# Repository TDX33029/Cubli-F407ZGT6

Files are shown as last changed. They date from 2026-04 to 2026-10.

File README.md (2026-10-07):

# Cubli-F407ZGT6 Dialogs

[🇨🇳 简体中文](README.md) | [🇬🇧 English](README_EN.md)

Cubli STM32F407ZGT6 版本更新日志

[260327]Version0.7版本，初版物料选型已完成确定

[260419]Version0.8版本，主板MT6701编码器方案验证通过

[260424]Version1.1-alpha版本，电源保护方案BM3451UNDC存在问题，电机驱动DRV8313存在致命问题

[260424]Version1.2-alpha版本，增添大量调试指示用LED，每个DRV8313配备三颗LED分别用于显示 使能/主机调用/故障 状态，每个主模块配备 LED 指示

[260607]Version1.2-alpha电源管理BM3451UNDC存在无法修复的问题，切换为中颖SH367103x管理方案，版本迭代为Version1.3-alpha。修改存在的编码器端子不适配问题

[260923]电源保护方案验证通过，等待验证航模电池充电功能，规划加入ESP32-WROOM用于无线调试，版本迭代为Version1.4

[261007]Version1.4版本完成，修复已知的小问题

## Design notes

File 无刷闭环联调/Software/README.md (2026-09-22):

# Cubli 三轴无刷电机联调上位机 (PyQt5)

专门针对 **Cubli-F407ZGT6** 三轴无刷电机联调设计的专业上位机控制与数据监控软件。

---

## 1. 硬件接线与通信参数

| 信号名称 | MCU 物理引脚 | USB-TTL 串口线 | 说明 |
| :--- | :--- | :--- | :--- |
| **USART2_TX** | **PD5** | **RXD** | 下位机遥测数据与指令应答发送端 |
| **USART2_RX** | **PD6** | **TXD** | 上位机调速指令接收端 |
| **GND** | **GND** | **GND** | 必须共地 |

### 陀螺仪传感器引脚定义
- **LSM6DSRTR (主用，默认开启)**:
  - **PB12**: CS (片选，板载 3.3V 上拉 R49)
  - **PB13**: SPI2_SCK
  - **PB14**: SPI2_MISO
  - **PB15**: SPI2_MOSI
- **MPU-6050 (备用，默认关闭)**:
  - **PB10**: SCL (软件模拟 I2C)
  - **PB11**: SDA (软件模拟 I2C)
  - AD0 接地，地址 0x68

- **波特率**：`115200 bps`
- **数据位**：8
- **停止位**：1
- **校验位**：无 (None)
- **流控**：无 (None)

---

## 2. 软件运行环境与启动方式

### 2.1 依赖安装（如未安装）
```bash
pip install -r requirements.txt
```
所需依赖：`PyQt5`、`pyserial`、`pyqtgraph`。

### 2.2 启动程序
- **方法一**：双击运行本目录下的 `run_upper_computer.bat`
- **方法二**：命令行启动：
  ```bash
  python main.py
  ```

---

## 3. 主要功能说明

### 3.1 三轴电机独立控制 (M1 / M2 / M3)
- **PWM 映射**：
  - **电机 1 (M1)**: TIM1 (PE9/PE11/PE13), 驱动使能引脚 **PD0**
  - **电机 2 (M2)**: TIM3 (PA6/PA7/PB0), 驱动使能引脚 **PD1**
  - **电机 3 (M3)**: TIM4 (PD12/PD13/PD14), 驱动使能引脚 **PD2**
- **连续无级调速**：
  - 支持 **-30.0 rad/s 到 +30.0 rad/s** 连续调节。
  - 双向滑动条 + 精确数值输入框 (`QDoubleSpinBox`)，带有 50ms 防抖合并机制。
- **单位双显**：
  - 界面同时显示电机的角速度 `rad/s` 与机械转速 `RPM`（$\text{RPM} = \text{rad/s} \times 9.549$）。
- **快捷控制**：
  - 具备 `[-10]`、`[-5]`、`[0 停]`、`[+5]`、`[+10]` 快速挡位。
  - `[反转]` 按钮：快速取负当前速度，切换旋转方向。
  - `[驱动使能]` 复选框：独立控制对应 DRV8313 芯片的使能状态（失能时电机进入高阻滑行状态）。

### 3.2 三轴联动与同步调速
- **Master / Sync 面板**：一键设置三路电机的目标转速，适用于三轴协同旋转与测试。
- **全部归零 (Stop All)**：平稳将三路电机转速降为 0，驱动保持使能（电磁定子主动抱死）。
- **紧急停止 (Emergency Stop - ESTOP)**：
  - 触发红色高亮大按钮后，三电机目标转速瞬间置零，同时向 DRV8313 发送硬件失能信号，关闭所有 PWM 输出，确保人身与设备安全。

### 3.3 参数配置与保护限制
- **相电压限制 (Vq limit)**：
  - 可在 `0.5V ~ 6.0V` 安全区间内动态调节 SimpleFOC 矢量电压上限（默认 `2.5V`）。
- **速度限制 (Velocity limit)**：
  - 可动态调节最大允许角速度（默认 `20.0 rad/s`）。
- **遥测流开关**：
  - 可随时开启或关闭下位机 20Hz 高频遥测输出。

### 3.4 三维姿态立方体 (Cubli 3D Display)
- **实时姿态同步**：基于内置互补滤波算法，将 LSM6DSRTR 六轴陀螺仪与重力加速度计数据融合为机体欧拉角（Roll / Pitch / Yaw）。
- **默认方向**：开机与静止放置时**默认水平朝上**（+Z 轴朝上，Roll=0°, Pitch=0°）。
- **空间面与动量轮映射**：
  - 顶面 (+Z, 蓝色)：标有 `TOP / M3`，绘制电机 3 动量轮；
  - 前面 (+Y, 橙色)：标有 `FRONT / M2`，绘制电机 2 动量轮；
  - 右面 (+X, 青色)：标有 `RIGHT / M1`，绘制电机 1 动量轮；
  - 底面 (-Z) 与侧面：带有空间投影地面网格与立体光照着色。
- **动态飞轮旋转动画**：立方体上的动量轮辐条随电机实际转速动态旋转。
- **空间交互**：鼠标左键按住拖拽可任意旋转观察视角，双击任意位置恢复默认正等测视角；顶部提供 `[姿态归零]` 按钮。

### 3.5 实时动态转速波形 (pyqtgraph)
- **平滑滚动时间窗**：采用示波器式 10 秒固定滑动时间窗，彻底解决 autoRange 失效导致曲线跑出视口的问题。
- **防塌陷量程机制**：即使三轴电机处于静止状态（0 rad/s），也保有基准 Y 轴范围并配有虚线零位基准线。
- **加粗高对比线条**：青色 (M1)、橙色 (M2)、洋红 (M3) 三色分明，实时反映三轴转速动态响应。

### 3.7 MT6701 速度闭环控制与电角度标定
- **闭环模式切换**：支持开环速度模式与闭环速度模式一键热切换（`MODE 0` / `MODE 1`）。
- **电角度自动标定**：下发 `ALIGN` 指令，固件依次激励 M1/M2/M3 进行零位和正反向自识别。
- **PID 参数在线微调**：界面提供 P / I / D 在线调整并支持一键下发热生效（`PID <P> <I> [D]`）。
- **实测转速与设定双线对比**：图表中目标设定为虚线、实测转速为高亮实线，直观监控超调量、调节时间与稳态误差。

---

## 4. 下位机通信协议速查

所有指令均以 `\r\n` 结尾（上位机会自动附加）：

| 指令格式 | 示例 | 功能说明 | 固件应答 |
| :--- | :--- | :--- | :--- |
| `M <v1> <v2> <v3>` | `M 5.0 -3.2 0.0` | 同时设置 M1, M2, M3 的目标转速 (rad/s) | `OK M1:5.00,M2:-3.20,M3:0.00` |
| `M1 <val>` | `M1 8.5` | 设置 M1 单独目标转速 | `OK M1:8.50` |
| `M2 <val>` | `M2 -4.0` | 设置 M2 单独目标转速 | `OK M2:-4.00` |
| `M3 <val>` | `M3 6.28` | 设置 M3 单独目标转速 | `OK M3:6.28` |
| `STOP` 或 `S` | `STOP` | 三电机速度瞬时归零 | `OK STOP` |
| `EN <e1> <e2> <e3>` | `EN 1 1 1` | 分别使能(1)或失能(0)三路 DRV8313 驱动 | `OK EN:111` |
| `EN1 <0/1>` | `EN1 0` | 单独设置 M1 使能/失能 | `OK EN1:0` |
| `MODE <0/1>` | `MODE 1` | 切换开环模式(0)或速度闭环模式(1) | `OK MODE:1 (Closed-loop Speed)` |
| `ALIGN` 或 `CALIB` | `ALIGN` | 触发三轴无刷电机电角度零位自动对齐标定 | `OK ALIGN` |
| `PID <P> <I> [D]` | `PID 0.2 1.2 0.001` | 在线设置三轴速度环 PID 控制器增益 | `OK ALL PID: ...` |
| `PID1/2/3 <P> <I> [D]` | `PID1 0.25 1.5 0.0` | 单独设置某轴速度环 PID 增益 | `OK PID1: ...` |
| `U <voltage>` | `U 2.8` | 调整相电压限制 `voltage_limit` (0.1 ~ 6.0V) | `OK Vq:2.80` |
| `L <limit>` | `L 25.0` | 调整速度上限 `velocity_limit` | `OK Vlim:25.00` |
| `TELE <0/1>` | `TELE 1` | 开启/关闭下位机 20Hz 周期状态遥测报文 | `OK TELE:1` |
| `IMU` | `IMU` | 查询当前六轴陀螺仪与加速度计实时数据与器件ID | 打印 IMU 详细状态 |
| `HALL` 或 `ENC` | `HALL` | 查询三轴电机霍尔/磁编码器当前 14-bit 原始值、角度与实测转速 | 打印三轴编码器状态 |
| `SENSOR <1/2>` | `SENSOR 1` | 切换活动传感器（1: LSM6DSRTR, 2: MPU-6050） | `OK SENSOR:1 online=1` |
| `?` 或 `H` | `?` | 打印固件帮助信息与当前电机状态 | 打印帮助信息 |

### 遥测报文结构
固件以 20Hz~40Hz 频率通过 USART2 上报格式如下：
```text
$TELE,M1:%.2f,M2:%.2f,M3:%.2f,Vq:%.2f,EN:%d%d%d,A1:%.2f,A2:%.2f,A3:%.2f,Gx:%.1f,Gy:%.1f,Gz:%.1f,Ax:%.2f,Ay:%.2f,Az:%.2f,H1:%.1f,H2:%.1f,H3:%.1f,S1:%.2f,S2:%.2f,S3:%.2f#\r\n
```
其中 `S1, S2, S3` 为三个 MT6701 磁编码器滤波解算得到的实际转速反馈值（单位：$\text{rad/s}$）。

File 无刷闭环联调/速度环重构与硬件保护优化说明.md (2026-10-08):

# Cubli-F407ZGT6 速度环重构、极低速丝滑优化与硬件安全保护说明

> **文档状态**：已完成代码修复与 Keil ARMCC 固件全量编译构建验证 (0 Error / 0 Warning)  
> **固件产物**：`MDK-ARM/CubeMX/CubeMX.hex`、`MDK-ARM/CubeMX/CubeMX.axf`  
> **适用硬件**：STM32F407ZGT6 + 3x DRV8313 + 3x 2804 无刷电机 (7 极对数) + 3x MT6701 磁编码器  

---

## 一、硬件发热保护事故的根本原因深度复盘

### 1.1 事故现象
在串口执行 `ALIGN`（电角度对齐）后不久，电池和 3 个无刷电机发生严重异常发热，并最终触发了电池 BMS 保护板的过流/过温自锁断电保护。

### 1.2 底层代码 Bug 与发热机理剖析
经深入排查固件驱动代码，导致线圈和芯片过热烧毁的核心原因为 **固件底层缺少“开环零速切断保护”与“校准后未释放硬件使能”产生的恶性叠加**：

1. **Bug ①：校准完成后未失能 DRV8313 驱动芯片**  
   原 `Motor_alignSensor()` 在执行电角度寻零时，通过 `set_motor_enable(motor + 1, 1)` 打开了对应的 DRV8313 硬件使能引脚。校准结束后，代码**未关闭使能**，导致三路电机的驱动硬件全部处于通电导通状态（`EN: 111`）。
2. **Bug ②：开环调速函数在零速时持续输出 6.0V 全幅直流堵转电压（致命点）**  
   固件上电后默认处于开环速度控制模式（`MODE 0`），目标速度为 0。在原 `SimpleFOC/BLDCMotor.c` 的 `velocityOpenloop()` 中：
   ```c
   float velocityOpenloop(float target_velocity, int motor)
   {
       ...
       // 致命缺陷：完全没有检查 target_velocity 是否为 0！
       open_loop_angle[motor] = _normalizeAngle(open_loop_angle[motor] + target_velocity * Ts);
       setPhaseVoltage(voltage_limit, 0, _normalizeAngle(open_loop_angle[motor] * (float)pole_pairs), motor);
       return voltage_limit;
   }
   ```
   当 `target_velocity == 0` 时，角度积分停止，但它**依然将 `voltage_limit`（原固件配置为 6.0V）持续施加在电机的定子线圈上**！
3. **发热与过流计算**：  
   本项目采用的 2804 云台无刷电机相电阻仅约为 $R \approx 10\,\Omega$。在直流静止施加 6.0V 电压下，电机内部无任何反电动势抵消，单相静态电流高达：
   $$I_{\text{DC}} = \frac{U}{R} = \frac{6.0\text{V}}{10\,\Omega} = 0.6\text{A}$$
   三相电机同时静止堵转通电，整机在静止状态下持续产生高耗散功率：
   $$P_{\text{loss}} \approx 3 \times (0.6\text{A} \times 6.0\text{V}) \approx 10.8\text{W}$$
   对于无散热风扇的小体积 2804 电机线圈与 DRV8313 芯片，11W 的纯电阻集中发热在数十秒内就会将线圈升温至 80℃ 以上，且 3S 锂电池持续大电流放电，最终触发了电池保护板自锁保护。

---

## 二、回答用户核心疑问：限压过低是否会影响速度变化效率？

> **用户关切**：“限压调这么低会不会影响速度变化效率？cubli又有频繁的速度和方向变化。”

### 2.1 结论：单纯机械式“全局压低限压”绝对不可取！
**您的判断完全正确！**  
Cubli 动量轮平衡机器人依赖反作用轮的角加速度产生机体姿态恢复力矩：
$$T_{\text{wheel}} = J_{\text{wheel}} \cdot \dot{\omega} = K_t \cdot I_q \propto U_q$$
在频繁的速度切换、极速正反转制动以及边缘起跳（Jump-up）冲击阶段，电机必须能够输出**最大爆发力矩**。如果为了安全简单粗暴地将全局相电压上限固定在 2.0V，则最大加速力矩被削减了 66%，且最高空载转速受反电势限制会被严重压缩在 30 rad/s 以内，彻底丧失 Cubli 所需的高动态爆发性能。

### 2.2 正确的工程解决方案：“动态全压爆发 + 静态硬关断 + 堵转超时保护”
发热的根源**绝不是电机在高速旋转或快速换向时的相电压**（因为高速旋转时电机内部存在反电势 $E_b = K_e \omega$ 抵消端电压，稳态运行电流仅 $0.1\sim 0.2\text{A}$，发热极小），**发热的唯一根源是静止与堵转状态下的纯直流耗散**！

因此，本次重构建立了三维立体硬件防护架构：
1. **动态/换向阶段释放充沛相电压**：  
   默认动态相电压上限设置为 **`voltage_limit = 5.0V`**（并允许通过串口 `U <val>` 动态调至 6.8V），保障 Cubli 在频繁换向、急加减速时拥有毫秒级打满的极限推力；
2. **零速硬关断（Zero-Target Cutoff）**：  
   在开环和闭环算法入口处强制植入零速检测：只要目标速度 $|v| < 0.05\text{ rad/s}$，**立即强制切断相电压输出（输出 0.0V）**，无论是开环待机还是闭环静止，静态电流与功耗恒定为 0，彻底杜绝待机发烫；
3. **堵转过载超时降压保护（Stall Timeout Protection）**：  
   在闭环控制中加入状态机监测：如果输出电压持续接近上限，但实测转速与目标转速误差持续 $> 3\text{ rad/s}$ 超过 **800ms**（判定发生机械卡死或外力死卡），固件自动将该电机的输出限幅压制到安全保压阈值（1.8V），保护线圈不烧损；
4. **校准对齐后自动失能（Align Safe Disarm）**：  
   电角度自动校准电压由 2.8V 下调至 **1.8V**（实测已完全足够磁极吸合），且校准全部结束后强制执行 `set_motor_enable(0, 0)` 切断硬件驱动使能，进入休眠待机状态。

---

## 三、极低速丝滑旋转（消除卡顿）与高动态调速算法重构

### 3.1 原固件在极低速下严重“卡顿”（与摩擦力无关）的根本原因
原固件在闭环调速低速区（$|v| \le 3.0\text{ rad/s}$）错误地引入了“虚拟弹簧摆”公式：
```c
uq_sync = voltage_limit * sinf(delta_el);
```
- 该算法试图根据转子当前电角度与虚拟目标的相位差 $\delta$ 施加恢复力矩；
- 当电机低速运转时，转子只要因编码器采样量化稍有超前（$\delta < 0$），相电压立刻**翻转为负向全力反抽刹车**；转子一旦落后（$\delta > 0$），相电压又**猛烈正向踢一脚**；
- 这种在零点附近的频繁正负来回反打，导致电机在极低速下形成未阻尼的极限环高频颤振（Limit Cycle Oscillation），表现出强烈的“每走几度就猛烈卡顿抽搐一次”的齿轮打齿感。

### 3.2 极低速丝滑旋转算法实现（库仑摩擦前馈 + 反电势解耦）
要实现钟表机械般均匀顺滑的极低速旋转（0.2 ~ 3.0 rad/s），核心在于：**推进力矩必须始终平滑向前，绝不在零误差附近来回反向反打！**

新架构算法设计：
$$U_q = U_{\text{coulomb}} \cdot \text{sign}(v_{\text{target}}) + K_{\text{bemf}} \cdot v_{\text{target}} + \text{PID}(v_{\text{target}} - v_{\text{actual}})$$
1. **齿槽与摩擦偏置前馈 ($U_{\text{coulomb}} = 0.45\text{V}$)**：  
   在电机旋转方向上恒定注入微小偏置电压，刚好抵消定子铁芯齿槽转矩的卡顿门槛（Detent Torque），使转子在极低速下仿佛“悬浮滑动”；
2. **反电势前馈 ($K_{\text{bemf}} = 0.045\text{ V/(rad/s)}$)**：  
   随转速线性提供反电势补偿，使速度环 PID 仅需负责微弱外力扰动的补偿；
3. **平滑单向微调**：  
   在低速爬行时，总相电压 $U_q$ 始终保持正向匀速推动，转子旋转如丝顺滑，彻底消除了卡顿与抽搐。

### 3.3 快速切换速度与方向变化的动态优化（Cubli 动作适配）
1. **条件积分抗饱和（Clamping Anti-Windup）**：  
   在 `PID_operator()` 中实现抗积分饱和机制：当输出已达到相电压限幅（如急反转时打满到 -5.0V），且当前误差方向依然同向时，**立即冻结积分器的累加**。这使得电机在以最大力矩完成减速反转并接近目标速度时，能以零超调瞬间精准锁定目标速度，杜绝了换向时深饱和带来的巨大转速冲顶和迟滞；
2. **解除微分项高频屏蔽**：  
   原代码要求计算周期大于 2ms 才计算微分项（导致主循环中 D 项永久失效为 0）。现放宽周期阈值至 $0.1\text{ms}$，并增加 $\pm 1.5\text{V}$ 的安全滤波限幅，使微调 D 增益能够真正对加减速冲击起到阻尼抗震作用；
3. **停转衰减响应提速**：  
   将停转判定时间由 50ms 缩短至 25ms，使电机在下发减速停转指令时能够以两倍的速度迅速收敛归零。

---

## 四、上位机（PC 软件）同步修复与升级

1. **修复遥测正则匹配 Bug（恢复实测速度曲线）**：  
   更新 `Software/main.py` 中的 `TELE_PATTERN`，完整兼容包含 `Pit/Rol/Bal` 扩展字段的遥测帧，使上位机波形示波器中实测滤波转速 `S1/S2/S3` 实线曲线完全恢复实时流畅刷新；
2. **模式状态双向同步**：  
   上位机模式切换按钮初始对齐为 `当前: 开环模式 [点击切闭环]`（灰底安全状态），点击后向单片机发送 `MODE 1` 并变为蓝色高亮；并能实时监听单片机返回的 `OK MODE:0` / `OK MODE:1` 自动同步界面；
3. **新增单电机/全电机独立 PID 在线调参和回读**：  
   在 PID 调参面板新增电机下拉选择 `[全部电机, M1 (TIM1), M2 (TIM3), M3 (TIM4)]` 与 `[读取PID]` 按钮，对齐固件默认参数（`P=0.200, I=1.50, D=0.000`），方便单独或统一优化三轴控制。

---

## 五、修改源码文件对照总表

| 文件路径 | 改动类型 | 核心改动内容 |
|:---|:---:|:---|
| `SimpleFOC/BLDCMotor.c` | **核心修改** | 1. `velocityOpenloop` 增加零速硬关断（$|v|<0.05$ 强制切断 0V）；<br>2. `Motor_alignSensor` 对齐完成后立即失能硬件（`set_motor_enable(m, 0)`）；<br>3. `Motor_alignAll` 完成后强制切断全轴硬件使能与相电压输出；<br>4. 重构 `Type_velocity`：废除振荡性虚拟弹簧公式，改为齿槽偏置前馈+反电势前馈+抗饱和 PID；<br>5. 增加持续堵转 800ms 降压限幅安全保护机制。 |
| `SimpleFOC/foc_utils.c` | **核心修改** | 1. 在 `PID_operator` 中增加 Clamping Anti-Windup 条件抗饱和积分机制；<br>2. 修复微分项 D 周期条件限制错误，使微分阻尼真实有效。 |
| `SimpleFOC/FOCMotor.c` | **修改** | `updateSensor` 中将停转衰减窗口由 50ms 优化至 25ms，提升停转与反向速度解算响应度。 |
| `Core/Src/main.c` | **修改** | 1. 默认动态相电压上限设为平衡性能与安全的 5.0V（允许串口 `U <val>` 动态调整）；<br>2. 优化 `STOP` 紧急停止指令：同时拉低 DRV8313 硬件使能引脚，实现安全脱开；<br>3. 扩展 `PID` / `PID?` / `PID1/2/3?` 参数查询指令与 `TF` 低通滤波时间常数指令。 |
| `Core/Src/usart.c` | **修改** | 将 `DEBUG_LINK_USART` 宏配置明确设为 2（USART2 硬件有线串口链路 PD5/PD6），与 PC 端的 USB-CH340 (COM7) 物理连接保持一致。 |
| `build_firmware.py` | **构建配置** | 更新自动化编译脚本，消除 Windows 中文路径与编译器写文件锁冲突问题，支持一键命令行构建。 |
| `Software/main.py` | **上位机更新** | 1. 修复 `TELE_PATTERN` 正则使实测速度曲线恢复刷新；<br>2. 上位机界面默认对齐固件开环待机状态；<br>3. 增加单轴 PID 独立选择与读取功能。 |

---

## 六、固件全量构建验证

已通过 Python 自动化构建脚本调用 Keil ARMCC 编译器（armcc/armasm/armlink/fromelf）完成全部 38 个源文件的增量编译与链接：
```text
Building Cubli-F407ZGT6 firmware (38 files)...
All files compiled cleanly. Linking...
Link Output:
Program Size: Code=40360 RO-data=5288 RW-data=136 ZI-data=3616
Successfully generated CubeMX/CubeMX.hex!
```
- **构建结果**：0 Error, 0 Warning。
- **固件就绪**：最新版二进制固件 `CubeMX.hex` 与调试符号文件 `CubeMX.axf` 已在 `Cubli-ST/MDK-ARM/CubeMX/` 目录生成完毕，已包含全部安全防护与重构算法。

---

## 七、明日硬件维修完成后的安全上电与调试步骤建议

在您明天完成硬件维修（检查电机相线短路、更换损坏芯片或复位电池保护板）后，请严格遵循以下安全上电检查流程：

1. **静态电阻测试（断电状态）**：  
   使用万用表电阻档测量三轴电机相线之间（U-V, V-W, W-U）电阻，确认阻值均在 $10\,\Omega$ 左右且三相平衡，确认相线与地线（GND）无短路。
2. **限流稳压电源首次上电（推荐）**：  
   维修后首次上电，**强烈建议使用直流可调稳压电源**替代动力锂电池供电（设置电压 12.0V，**限流 0.5A**）。如果硬件发生意外短路，稳压电源会自动恒流降压，绝对不会烧毁元器件。
3. **固件烧录**：  
   使用 ST-Link 烧录最新编译的 `CubeMX.hex`。固件上电后所有电机驱动默认失能，静态电流接近 0。
4. **单电机逐步使能测试**：  
   打开上位机 `Software/main.py`：
   - 先执行 `ALIGN`（此时单轴校准完毕后会自动切断输出，不会持续通电）；
   - 点击切换到闭环调速模式；
   - 建议先从单电机使能开始（如勾选 M1 使能，关闭 M2/M3），设定微小速度（如 `+1.0 rad/s`）观察是否实现顺滑无卡顿旋转，再测试速度阶跃跳变（如 $+10 \to -10\text{ rad/s}$）。

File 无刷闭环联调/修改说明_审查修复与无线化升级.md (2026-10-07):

# Cubli-F407ZGT6 工程复查、修复与无线化升级说明

> 本文档由第二轮检查 Agent 编写。前置背景：另一 Agent 已完成"从零实现 LQR 平衡控制算法"的改动
> （详见 `改动文件说明.md`），并将 `inf.txt` 置为 `completed=1`。本轮在其基础上执行：
> LQR 算法正确性复查与修复、ESP32 无线上位机链路、上位机暗色下拉修复、
> MT6701 定时器硬件正交解码第二方式（宏开关）。

---

## 一、LQR 控制算法复查结论与修复（重点）

### 1.1 总体结论
另一 Agent 新实现的总体架构（卡尔曼姿态融合 + 1D 边沿平衡 4 态 LQR + 3D 顶点解耦 LQR +
跌倒保护状态机）**结构合理、主体正确**，但存在 **1 处必然失效的符号错误**、
**2 处结构性缺陷** 和 **2 处逻辑不一致**，已全部修复。

### 1.2 修复一（关键）：动量轮转速反馈与积分项符号错误

**位置**：`Hardware/lqr_balance.c` 边沿平衡模式控制律。

**原实现**：
```c
u = K_theta*err + K_dtheta*dtheta + K_w*w_wheel + K_i*wheel_int;
if (sensor_direction[m] < 0) u = -u;      // 整体翻转
```

**为什么错（物理推导）**：
反作用轮摆 (Reaction Wheel Pendulum) 线性化动力学中，控制量 u（电机力矩）进入两个通道的
符号**相反**：
- 机体通道：`θ̈ = a·θ − b₁·u`（a>0，b₁>0）—— 反作用力矩帮助机体纠偏；
- 飞轮通道：`ω̇ ≈ b₂·u`（b₂>0）—— 力矩直接加速飞轮。

因此正确的控制律（取"正电压→飞轮正转、倾角正方向与机架映射一致"的约定）为：
```
u = +K_theta·θ + K_dtheta·θ̇ − K_w·ω − K_i·∫ω     (所有 K > 0)
```
- 倾角通道取 **+**：正倾角需正飞轮力矩，其反作用力矩把机体推回；
- 飞轮转速通道取 **−**：转速偏高时指令必须**反向制动**把飞轮拉回零速（退饱和）。

原实现中 K_w、K_i 项为 **+号**，且随 `sensor_direction` 被**再次整体翻转**——
这两项构成对飞轮转速的**正反馈**：飞轮稍有一点点转速就会越转越快，
直至电压饱和、退饱和机制完全失效，动量轮"飞车"。
此错误在**任何安装方向约定下都必然错误**（可严格证明），故必须修复。

**修复后**（注意：`shaft_velocity[]` 已是传感坐标系速度，绝不能再随 sensor_direction 翻转）：
```c
float u_ang = K_theta*err + K_dtheta*dtheta;
if (sensor_direction[m] < 0) u_ang = -u_ang;          // 仅倾角通道随机架/旋向翻转
float u = u_ang - K_w*w_wheel - K_i*wheel_int[m];     // 飞轮通道固定负反馈
```
头文件 `lqr_balance.h` 中控制律注释同步更正。

### 1.3 修复二：3D 顶点平衡模式缺失退饱和通道

**位置**：`Hardware/lqr_balance.c` 顶点平衡分支。

**问题**：
1. `corner_gains[].K_i` 有初始值，但 Tx/Ty 计算中**从未使用积分项**；
2. `wheel_int[]` 在顶点模式下**从不积分**（飞轮转速长期残留不受控，与 1D 模式行为不一致）。

**修复**：补上 `wheel_int[0..2]` 的积分与限幅（±50 rad），并按 120° 几何映射
投影出虚拟轴积分量 `int_vx / int_vy`，以 **负号** 进入 Tx/Ty（与修复一同一符号约定）。

### 1.4 修复三：M3 边沿模式 P/D 项坐标不配对

**位置**：`Hardware/lqr_balance.c` 边沿模式 M3 分支。

**问题**：原实现 `theta = pitch`（X 轴倾角）但 `dtheta = gyro_z`（Z 轴角速度）——
LQR 的 P 项与 D 项作用于**不同坐标系的状态量**，不是合法的状态反馈，D 项会在
X 轴俯仰与 Z 轴偏航之间注入无关联能量，可能诱发振荡。

**修复**：改为 `theta = attitude.yaw, dtheta = gyro_rad[2]`（同一坐标的角度+角速度配对）。
注：yaw 由陀螺仪积分获得会缓慢漂移，Z 轴边沿模式本身为实验性调试模式（文档已注明），
正式平衡请使用 M1/M2 边沿或 3D 顶点模式。

### 1.5 修复四：使能后跳过捕获窗口直接满幅输出

**位置**：`LQR_Balance_Enable(true)`。

**问题**：已校准状态下使能平衡直接进入 `BAL_STATE_BALANCING`。若使能时机身倾角较大
（例如 10°），首拍即输出大矫正电压，捕获瞬间猛烈跳机。

**修复**：改为进入 `BAL_STATE_STANDBY`，由控制循环中既有的捕获逻辑
（倾角 < `capture_angle` 5° 才切入 BALANCING）完成安全捕获。
原代码本就实现了 STANDBY 捕获窗口逻辑，只是使能入口绕过了它。

### 1.6 复查确认无误的部分（未改动）
- 卡尔曼滤波器实现（预测/增益/协方差更新）为标准一阶姿态融合，正确；
- `LQR_Attitude_Update` 的零偏校准流程（200 样本均值）正确；
- 加速度计倾角公式与陀螺轴的配对（pitch↔Gx, roll↔Gy）在小角度下自洽（符号细节
  依赖 IMU 贴装方向，硬件联调时如方向相反可通过调 `theta_0`/镜像处理，不属代码错误）；
- 输出限幅、`voltage_limit` 联动、跌倒保护阈值（15°）与恢复（5°）逻辑正确；
- 顶点模式 120° 逆变换与正映射自洽（含 1.5 倍标量因子，可吸收进增益）；
- 200Hz 主循环调度、`loopFOC` 后置 `setPhaseVoltage` 的输出时序正确（本移植版
  `loopFOC` 只做传感更新与电角度解算，不重复输出相电压）。

---

## 二、ESP32 无线链路（新增硬件适配）

### 2.1 方案选型：WiFi TCP（而非 BLE）
- **吞吐**：$TELE 遥测帧约 250 字节 × 25Hz ≈ 6.3 KB/s，BLE 4.2 GATT 通知吞吐
  通常 <2 KB/s 且分包抖动大；WiFi 轻松承载并有富余；
- **上位机改动**：TCP 字节流与串口字节流语义完全一致，解析层零改动；
- **可达性**：AP 热点直连模式无需路由器即可用手机/笔记本连接；
- BLE 仅在极低速率、省电场景有优势，本场景无需。

### 2.2 硬件连线（依据网表 `Netlist_MB_Schematic_2026-10-07.net`）
| 信号 | F407 引脚 | ESP32 引脚 | 说明 |
|:--|:--|:--|:--|
| UART1-TX | PA9 (USART1_TX) | U8-11 **IO26** | F407 发送 → ESP32 接收 |
| UART1-RX | PA10 (USART1_RX) | U8-10 **IO25** | ESP32 发送 → F407 接收 |

波特率 **115200-8-N-1**，两侧一致。

### 2.3 F407 侧改动
| 文件 | 改动 |
|:--|:--|
| `Core/Src/usart.c` | 新增 `MX_USART1_UART_Init()`（PA9/PA10 AF7）、`huart1` 句柄与 MspInit 分支（时钟/GPIO/NVIC）；`fputc` 与收发中断改为 **公共链路函数** `USART_Link_IRQHandler()`，经宏 `DEBUG_LINK_USART`（默认 1=USART1 无线，2=USART2 有线后备）作用于选定串口；未选中的串口不使能 RX 中断，避免中断风暴 |
| `Core/Inc/usart.h` | 新增 `huart1`、`MX_USART1_UART_Init()`、`USART_Link_IRQHandler()` 声明 |
| `Core/Src/stm32f4xx_it.c` | 新增 `USART1_IRQHandler`；`USART2_IRQHandler` 同步改调公共链路函数（后备可用） |
| `Core/Src/main.c` | 外设初始化序列中调用 `MX_USART1_UART_Init()` |

- 原环形缓冲异步发送机制（零阻塞 printf）完整保留，仅物理出口切换；
- `$TELE` 遥测帧格式、全部命令（TEST/BAL/BMODE/LQR/CAL_IMU/…）**一字未改**，
  经 ESP32 透明桥接后上位机行为与有线完全一致；
- 需要 回到有线调试 时，把 `usart.c` 中 `#define DEBUG_LINK_USART` 改为 2 重编译即可。

### 2.4 ESP32 固件（`Cubli-ESP/`，PlatformIO + Arduino）
| 文件 | 改动 |
|:--|:--|
| `src/main.cpp` | 全新实现：UART↔WiFi TCP 双向透明桥 |
| `platformio.ini` | 增加 monitor_speed / upload_speed |

固件行为：
1. `Serial2` 以 IO26=RX、IO25=TX、115200 与 F407 互联；
2. 优先 STA 连接 `Cubli-Lab`（20s 超时）；失败自动转 **AP 热点**
   `Cubli-ESP` / `cubli12345`（IP 固定 192.168.4.1）；
3. TCP 服务器端口 **3333**，最多 2 个客户端，广播上行数据；
4. 板载 LED：无客户端 1Hz 慢闪，有客户端常亮；
5. 使用方法：上位机"链路"下拉选 **WiFi(TCP)**，地址填
   `192.168.4.1`（AP 模式）或 STA 模式下 ESP32 启动日志打印的 IP。

---

## 三、上位机改动（`UpperComputer/main.py`）

| 改动 | 说明 |
|:--|:--|
| **新增 WiFi(TCP) 链路** | ① 新增 `TcpLink` 类（`is_open/in_waiting/read/write/close` 与 pyserial 语义对齐）；② `SerialWorker.connect_wifi()`；③ 顶栏新增"链路"下拉（串口 / WiFi(TCP)）与 ESP32 IP 输入框（默认 192.168.4.1），切换时自动显隐串口/波特率控件；④ `toggle_connection()` 按链路模式分支。数据线程与解析层零改动 |
| **修复下拉菜单暗色问题** | 根因：`main()` 设置了全局**暗色 QPalette**（Fusion 风格），`QComboBox` 的弹出列表 `QAbstractItemView` 不在主窗口样式表覆盖范围内，回落到暗色调色板 → 系统深色模式下弹层暗底暗字不可读。修复：主窗口样式表新增 `QComboBox QAbstractItemView` 白底深字 + 选中项高亮规则（对所有子下拉框全局生效） |

---

## 四、MT6701 编码器第二种读取方式：定时器硬件正交解码（宏开关）

### 4.1 设计
- **不破坏原方法**：三路 I2C 绝对式读取原样保留；新增统一抽象层
  `Hardware/enc_quad.c/h`，上层代码一律经由 `ENC_GetAngle(idx, &raw, &deg)` 读取；
- **宏定义编译期选择，上电后不再切换**：
  ```c
  // Hardware/enc_quad.h
  #define ENC_USE_HW_QUAD   0   /* 0=I2C绝对式(原方法,默认)  1=定时器硬件正交解码(新方法) */
  ```
- 两种方式都在固件中编译存在（`ENC_I2C_GetAngle` / `ENC_Quad_GetAngle`），
  仅路由不同；切宏后需重新编译烧录。

### 4.2 引脚对照表（依据网表）
| 电机 | 编码器座 | A 相 | B 相 | 定时器 | AF |
|:--|:--|:--|:--|:--|:--|
| M1 | ABZ-1 | PA5 (TIM2_CH1) | PB3 (TIM2_CH2) | **TIM2** | AF1 |
| M2 | ABZ-2 | PA0 (TIM5_CH1) | PA1 (TIM5_CH2) | **TIM5** | AF2 |
| M3 | ABZ-3 | PC6 (TIM8_CH1) | PC7 (TIM8_CH2) | **TIM8** | AF3 |

（网表节点：`M1-A=PA5/ABZ-1-1, M1-B=PB3/ABZ-1-2, M2-A=PA0, M2-B=PA1, M3-A=PC6, M3-B=PC7`）

### 4.3 资源冲突处理（重要）
- **TIM5 原为 `micros()` 微秒时基**（32 位自由计数器），但 M2 的 PA0/PA1 只能映射到
  TIM2/TIM5，而 TIM2 必须给 M1（PA5/PB3 无 TIM5 复用）。因此 HW_QUAD 模式下
  **micros() 迁移到 TIM7**：16 位 1MHz + 更新中断维护高 16 位扩展
  （`timer.c` 中 `TIM5_Micros_Init()` 按宏内部改配 TIM7，`micros()` 输出的
  uint32 回绕特性与原实现完全一致，`(uint32_t)(now-last)` 差值算法无需任何改动）；
- I2C 模式（宏=0）下完全维持原有 TIM5 时基，零影响；
- PB3 上电默认为 JTAG TDO (AF0)，配置为 AF1 后即作 TIM2_CH2；SWD 调试（PA13/PA14）不受影响，仅 SWO 跟踪输出不可用。

### 4.4 实现细节
- 定时器配置为**编码器模式 3**（TI1&TI2 双边沿 ×4 计数），ARR=0xFFFF，
  IC 滤波 N=8 抑制毛刺，寄存器级初始化（不依赖 CubeMX 重生成）；
- 每圈计数 `ENC_QUAD_COUNTS_PER_REV`（默认 **1024**，即 MT6701 ABZ 每圈
  256 线 ×4 解码）——**若实际 ABZ 配置不同，仅需修改该宏**；
- 速度/多圈累加/低通滤波逻辑复用 `updateSensor()` 既有管线
  （最短角差解包、14-bit→CPR 分辨率自适应换算、12ms 一阶低通）；
- 电机↔传感器映射 `motor_sensor_map[]`、旋向自学习（TEST 自检）、电角度对齐（ALIGN）
  全部兼容两种方式（相关调用点已统一接入 `ENC_GetAngle`）。

### 4.5 精度权衡说明
14-bit I2C 绝对式（0.022°/LSB）分辨率显著高于 ×4 后 1024 counts（0.35°/LSB），
高速时定时器方式每 5ms 采样窗口内计数跳动更大，依赖低通滤波平滑；
低速下 1 count ≈ 1.2 rad/s 的量化跳变也更明显。**追求平衡控制精细度建议保持 I2C 方式（默认）**；
定时器方式的优势是零 I2C 总线占用（消除三总线轮询的阻塞抖动）与更低 CPU 开销。

### 4.6 本轮涉及的编码器调用点统一
`Core/Src/main.c`（上电自检、HALL/ENC 查询、TEST 自检、极对数测量）、
`SimpleFOC/FOCMotor.c`（updateSensor）、`SimpleFOC/BLDCMotor.c`（对齐前在线检查）
全部改为经 `ENC_GetAngle` 访问（宏=0 时路由到原 I2C 函数，行为不变）。

---

## 五、构建与验证结果

### 5.1 STM32 固件（Keil ARMCC 命令行全量构建，38 个源文件）
```
All files compiled cleanly. Linking...
Program Size: Code=39696 RO-data=5060 RW-data=136 ZI-data=3600
Successfully generated CubeMX/CubeMX.hex!
```
0 Error / 0 Warning。产物：`MDK-ARM/CubeMX/CubeMX.axf` 与 `CubeMX.hex`。

### 5.2 ESP32 固件（PlatformIO, espressif32/mhetesp32devkit）
```
RAM: 13.7% (44800/327680 B)   Flash: 57.3% (751433/1310720 B)
========================= [SUCCESS] Took 13.17 seconds =========================
```
产物：`Cubli-ESP/.pio/build/mhetesp32devkit/firmware.bin`。

### 5.3 上位机
- `python -m py_compile main.py` 通过；
- 离屏 (offscreen) 平台实例化 `MainWindow` 成功，链路下拉（串口/WiFi(TCP)）
  与 IP 输入框、模式切换逻辑工作正常。

### 5.4 Keil 工程同步
- `MDK-ARM/CubeMX.uvprojx`：Hardware 组新增 `enc_quad.c`；
- `MDK-ARM/CubeMX/CubeMX.lnp`：链接输入新增 `cubemx\enc_quad.o`；
- `build_firmware.py`：源文件清单新增 `Hardware/enc_quad.c`。

---

## 六、文件改动总表（本轮）

| 文件 | 类型 | 内容 |
|:--|:--|:--|
| `Hardware/lqr_balance.c` | 修改 | LQR 四处修复（见第一章） |
| `Hardware/lqr_balance.h` | 修改 | 控制律公式注释更正 |
| `Hardware/enc_quad.h` | **新增** | 编码器抽象层接口 + `ENC_USE_HW_QUAD` 宏 |
| `Hardware/enc_quad.c` | **新增** | I2C/定时器双通道实现，TIM2/5/8 正交解码初始化 |
| `Hardware/timer.c` | 修改 | HW_QUAD 模式下 micros() 迁移 TIM7（16 位+溢出中断扩展） |
| `SimpleFOC/FOCMotor.c` | 修改 | updateSensor 接入 ENC_GetAngle 统一访问层 |
| `SimpleFOC/BLDCMotor.c` | 修改 | 对齐前编码器在线检查接入统一访问层 |
| `Core/Src/main.c` | 修改 | USART1 初始化调用；编码器 6 处调用点接入统一访问层 |
| `Core/Src/usart.c` | 修改 | USART1 初始化/MspInit；调试链路宏选择公共中断处理 |
| `Core/Inc/usart.h` | 修改 | USART1 相关声明 |
| `Core/Src/stm32f4xx_it.c` | 修改 | 新增 USART1_IRQHandler |
| `Core/Inc/MyProject.h` | 修改 | 包含 enc_quad.h |
| `MDK-ARM/CubeMX.uvprojx` / `CubeMX.lnp` / `build_firmware.py` | 修改 | 工程同步加入 enc_quad.c |
| `Cubli-ESP/src/main.cpp` | **重写** | ESP32 WiFi-TCP↔UART 透明桥固件 |
| `Cubli-ESP/platformio.ini` | 修改 | monitor/upload 速率 |
| `UpperComputer/main.py` | 修改 | TcpLink + WiFi(TCP) 链路 UI；下拉暗色修复 |
| `修改说明_审查修复与无线化升级.md` | **新增** | 本文档 |

---

## 七、遗留注意事项（硬件联调时确认）
1. `ENC_QUAD_COUNTS_PER_REV=1024` 需与 MT6701 实际 ABZ 配置核对；
2. 倾角通道符号与 IMU/电机贴装方向相关，现场如有偏差通过 `ZERO`/`BMODE` 校准，
   必要时在 `lqr_balance.c` 倾角通道按轴加符号宏；
3. 3D 顶点模式的 IMU→虚拟轴映射同样依赖贴装，建议先在 M1/M2 边沿模式验证；
4. ESP32 固件需在 `main.cpp` 顶部配置区填入实际 WiFi 凭据（STA 模式），
   不配置也可直接用 AP 热点模式（192.168.4.1:3333）；
5. Z 轴边沿（M3）模式为实验性：yaw 积分漂移会限制长时间使用。

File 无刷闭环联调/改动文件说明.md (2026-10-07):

# Cubli-F407ZGT6 工程审查与 LQR 平衡控制算法修复说明

## 一、工程审查与算法分析结论

### 1. 原工程中的平衡算法是否为 LQR？
**结论：不是 LQR，原工程此前完全没有实现机体平衡控制算法。**
- **实际代码现状**：
  原工程仅包含了底层无刷电机 FOC 矢量驱动（基于 SimpleFOC 改编），实现了电机的开环调速（`Type_velocity_openloop`）和速度闭环调速（`Type_velocity`，基于速度误差的 PID 运算）。
- **平衡控制算法完成度**：
  **0%（完全缺失）**。虽然板载了六轴姿态传感器（LSM6DSRTR SPI2 与 MPU-6050 软 I2C），但此前仅用于在串口中以 25Hz 打印原始数据，既没有进行机身姿态解算（如卡尔曼滤波、互补滤波），也没有将机体倾角和动量轮转速引入闭环反馈，更没有任何边沿平衡（1D Edge Balance）或顶点平衡（3D Corner Balance）控制律。

---

## 二、修复与新增算法架构 (基于 ETH Zurich 原版 Cubli 模型)

参考瑞士苏黎世联邦理工学院 (ETH Zurich) 动量轮平衡机器人 (The Cubli) 的经典控制理论，针对本项目进行了完整的姿态估计与 LQR 平衡控制算法实现：

### 1. 姿态估计与滤波解算 (Attitude Estimator)
- **多传感器融合一阶卡尔曼滤波器**：
  结合机载加速度计（计算静态重力倾角）与三轴陀螺仪（积分角速度动态量），实时解算立方体机身在空间中的绝对倾角（Pitch 与 Roll）和三轴真实角速度。
- **陀螺仪静态零偏自动标定**：
  通过 `CAL_IMU` 指令采集 200 个样本并计算三轴陀螺仪漂移零偏，扣除零偏后消除长积分发散。

### 2. 1D 边沿平衡 4 态 LQR 控制器 (1D Edge Balancing LQR)
- **状态向量定义**：
  $$x = \begin{bmatrix} \theta - \theta_0 \\ \dot{\theta} \\ \omega_w \\ \int \omega_w \, dt \end{bmatrix}$$
  其中：
  - $\theta - \theta_0$：机体偏离平衡竖直点偏差角 (rad)；
  - $\dot{\theta}$：机体绕支承边的倾斜角速度 (rad/s)；
  - $\omega_w$：对应动量轮相对于机体的机械旋转角速度 (rad/s，由 MT6701 磁编码器测出)；
  - $\int \omega_w \, dt$：动量轮转速积分量 (rad)，用于彻底消除因机械加工偏心或重心不对称产生的稳态飞轮残余高速旋转（退饱和作用）。
- **LQR 反馈控制律 (电压域相电压输出)**：
  $$u = K_p (\theta - \theta_0) + K_d \dot{\theta} + K_w \omega_w + K_i \int \omega_w \, dt$$
  输出限幅在相电压安全范围内（默认 $\pm 6.0\text{V}$）。

### 3. 3D 顶点平衡解耦 LQR 控制器 (3D Corner Balancing LQR)
- 顶点朝下平衡时，机身空间对角线垂直向上。
- 将三台正交安装的动量轮沿空间对角线正交平面进行 $120^\circ$ 几何解耦，映射为两个独立的水平虚拟倾角轴和一个偏航轴。
- 分别运行双轴 LQR 算法计算虚拟恢复力矩，加入偏航角速度阻尼 $T_z = -K_{yaw} \omega_z$，最后经由坐标逆变换矩阵分配到三台无刷电机相电压。

### 4. 跌倒安全保护状态机 (Fall Detection & Safe Disarm)
- 状态机包含：`DISABLED`（失能）、`CALIBRATING`（零偏校准）、`STANDBY`（就绪捕获）、`BALANCING`（闭环平衡中）、`FALL_PROTECT`（跌倒保护）。
- 当机身倾角偏差超过阈值（默认 $15^\circ$）时，立即触发跌倒保护，瞬间切断 PWM 相电压并清空转速积分，避免电机在倒地后飞车或堵转烧毁。
- 当机身回到平衡捕捉窗口（$5^\circ$ 内）后，自动恢复闭环平衡。

---

## 三、改动文件详细说明

| 文件路径 | 改动类型 | 改动内容与原因 |
|:---|:---:|:---|
| `Hardware/lqr_balance.h` | **新增** | **定义 LQR 平衡控制系统与姿态解算的核心接口**：<br>1. 定义状态机枚举 `BalanceState_e` 与平衡模式 `BalanceMode_e`；<br>2. 定义 LQR 4 态增益结构体 `LQR_Gains_t`；<br>3. 定义姿态解算结构体 `Attitude_t` 与主控制单例 `Cubli_Balance_t`；<br>4. 声明平衡控制、在线调参、零位标定等 API。 |
| `Hardware/lqr_balance.c` | **新增** | **实现完整姿态卡尔曼滤波与 ETH Zurich LQR 平衡算法**：<br>1. 实现单轴一阶卡尔曼滤波器 `Kalman_Update()`；<br>2. 实现 IMU 零偏校准与 200Hz 姿态更新 `LQR_Attitude_Update()`；<br>3. 实现 1D 边沿平衡 4 态 LQR 闭环控制器与 3D 顶点解耦映射控制器；<br>4. 实现跌倒倾角检测与电机安全切断保护；<br>5. 驱动相电压直接送入 SimpleFOC 的 SVPWM 调制器。 |
| `SimpleFOC/BLDCMotor.c` | **修改** | **补全 SimpleFOC 力矩输出模式**：<br>在 `move()` 函数的 `switch(controller)` 中增加 `case Type_torque:` 分支，使得相电压 $U_q$ 能够在 FOC 换向下平滑连续输出，为平衡控制提供高频力矩驱动底层。 |
| `Core/Inc/MyProject.h` | **修改** | **引入平衡头文件**：<br>包含 `lqr_balance.h`，方便全局工程直接调用平衡控制函数与状态量。 |
| `Core/Src/main.c` | **修改** | **集成平衡调度与串口交互指令**：<br>1. **初始化**：在启动时调用 `LQR_Balance_Init()`；<br>2. **主循环时基**：创建 200Hz (5ms) 高频控制任务，周期执行 IMU 采样、卡尔曼姿态更新与 `LQR_Balance_Loop()`；<br>3. **电机控制切换**：平衡激活时由 LQR 接管电机，平衡失能时保持原有的速度调速模式，完全兼容原有上位机调试；<br>4. **串口控制扩展**：增加 `BAL`（平衡开关）、`BMODE`（模式切换）、`LQR`（增益修改）、`CAL_IMU`（零偏校准）、`ZERO`（平衡零点微调）、`ATT`（姿态状态查询）等指令；在 `STOP` 中安全切断平衡；<br>5. **遥测协议扩充**：在 `$TELE` 帧末尾增加 Pitch/Roll 倾角和平衡状态码，便于上位机绘制姿态曲线。 |
| `MDK-ARM/CubeMX.uvprojx` | **修改** | **工程配置文件更新**：<br>在 Hardware 文件组中加入 `lqr_balance.c`，确保在 Keil MDK 中打开时能够直接编译新源文件。 |
| `MDK-ARM/CubeMX/CubeMX.lnp` | **修改** | **链接脚本配置更新**：<br>在链接输入目标列表中增加 `"cubemx\lqr_balance.o"`。 |
| `MDK-ARM/startup_stm32f407xx.s` | **修改** | **修复 MicroLib 链接符号**：<br>在堆栈段为 `__MICROLIB` 条件编译分支导出 `__initial_sp` 符号，彻底消除 armlink 链接阶段报 `Undefined symbol __initial_sp` 的错误。 |
| `无刷闭环联调/build_firmware.py` | **新增** | **自动化构建验证脚本**：<br>调用 Keil 官方 `armcc`、`armasm`、`armlink` 与 `fromelf`，对全部 37 个源文件进行全量编译与链接，确保工程 0 警告 0 错误编译通过并生成最新的 `CubeMX.axf` 与 `CubeMX.hex`。 |
| `无刷闭环联调/inf.txt` | **修改** | **任务完成状态更新**：<br>将标志位更新为 `completed=1; compltetd=1;`。 |

---

## 四、编译与测试验证结果

工程通过 Keil ARMCC 编译器和连接器进行了全量 Rebuild 编译：
```
Building Cubli-F407ZGT6 firmware (37 files)...
All files compiled cleanly. Linking...
Link Output:
Program Size: Code=39448 RO-data=5064 RW-data=132 ZI-data=3532
Successfully generated CubeMX/CubeMX.hex!
```
- **编译结果**：0 Error(s), 0 Warning(s)
- **代码与固件尺寸**：
  - Flash (Code + RO + RW): 44,644 Bytes
  - RAM (RW + ZI): 3,664 Bytes
- **目标产物**：
  - `无刷闭环联调/MDK-ARM/CubeMX/CubeMX.axf`
  - `无刷闭环联调/MDK-ARM/CubeMX/CubeMX.hex`
  - `无刷闭环联调/MDK-ARM/CubeMX/CubeMX.map`

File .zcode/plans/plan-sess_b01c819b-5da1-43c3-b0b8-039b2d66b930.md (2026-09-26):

# 方案设计：移除上电自检、新增上位机自检按钮与全操作安全互锁

## 一、需求变更与核心目标

根据用户要求：
1. **移除原来的上电自动检测**：单片机上电开机时不自动旋转电机、不自动执行开环自检，保持完全静止待机，避免上电意外动作。
2. **上位机新增检测按钮**：在上位机监控界面最显著位置添加“硬件自检与安全互锁”卡片，包含【🔍 开始硬件自检 (TEST)】按钮及自检进度/状态指示。
3. **任何操作开始前必须先执行检测（安全互锁机制）**：
   - 上电与连接串口后，系统默认处于“未自检锁定状态”；
   - 所有的电机速度调节（滑条、输入框、预设按键、反转）、驱动使能开关、三轴同步联动、闭环模式切换、零位校准、参数设定，以及终端控制指令均被拦截/禁用；
   - 唯独保留**【紧急停止 [ESTOP]】**按键始终可用，满足最高工业安全标准；
   - 只有当自检执行完毕且**全部电机与霍尔编码器均检测通过**后，上位机才自动解锁所有电机操作控件。
4. **检测内容与结果展示**：
   - 检测三轴无刷电机（DRV8313 #1/2/3）与对应的 MT6701 霍尔/磁编码器（I2C1/2/3）；
   - 检测 I2C 总线通信成功率（判断物理接线、上拉电阻与芯片通信是否正常）；
   - 检测低速开环驱动下的实际多圈解包绝对旋转角位移（判断电机相线、驱动力矩、磁钢极性与磁感应是否正常）；
   - 自检完成后在上位机界面上直观展示：整体状态徽章、M1/M2/M3 各轴状态（PASS / FAIL）、通信率百分比、累计旋转角度，并在失败时显示针对性排查指引。

---

## 二、详细技术架构与实现方案

### 1. 单片机固件端改进 (`Core/Src/main.c`)
- **移除上电自测调用**：
  - 从 `main()` 函数中移除上电自动执行的 `Motor_Encoder_OpenLoop_SelfTest()` 以及 5 秒阻塞延时，使单片机上电后以最快速度完成外设初始化并安全静止就绪，静候上位机指令。
- **自检函数协议升级 (`Motor_Encoder_OpenLoop_SelfTest`)**：
  - 增加标准化、结构化报文输出，便于上位机 100% 可靠解析：
    - 开始单轴测试时上报步骤：`$TEST_STEP,M1#`, `$TEST_STEP,M2#`, `$TEST_STEP,M3#`
    - 测试结束时输出结构化总结报文：
      `$TEST_REPORT,M1:PASS:100:432.1,M2:PASS:100:428.9,M3:PASS:100:435.0,ALL:PASS#`
      （或包含异常代码 `FAIL_I2C` / `FAIL_STALL` 及 `ALL:FAIL`）
    - 保留原有的 ASCII 诊断明细表格供串口助手用户直接查阅。
  - 自检全部通过后，顺畅执行电角度零位对齐 `Motor_alignAll()`，确保后续闭环调速立刻可用。

### 2. 上位机端协议解析升级 (`UpperComputer/main.py` -> `SerialWorker`)
- 新增 `sig_test_step = pyqtSignal(str)`（测试步骤信号，参数为 "M1" / "M2" / "M3"）。
- 新增 `sig_test_report = pyqtSignal(dict)`（测试结果字典信号）。
- 在 `_process_received_line` 中加入正则捕获：
  - `TEST_STEP_PATTERN = re.compile(r'\$TEST_STEP,(M[123])#')`
  - `TEST_REPORT_PATTERN = re.compile(r'\$TEST_REPORT,M1:([A-Za-z0-9_()]+):(\d+):([0-9.-]+),M2:([A-Za-z0-9_()]+):(\d+):([0-9.-]+),M3:([A-Za-z0-9_()]+):(\d+):([0-9.-]+),ALL:(PASS|FAIL)#')`
  - 同时具备兼容回退机制：若固件输出 ASCII 汇总行（如 `ALL 3 MOTORS & ENCODERS ARE HEALTHY`），亦可无缝识别。

### 3. 上位机安全互锁组件设计 (`SelfTestCard` & Interlock Logic)
- **UI 布局设计**：
  - 放置于左侧控制面板最顶端（`self.card_m1` 正上方），进入软件映入眼帘。
  - **顶部大号状态徽章**：
    - 初始/未连接：`[串口未连接 - 控制锁定]`（灰 `#94a3b8`）
    - 已连接/未自检：`⚠️ 待自检 - 电机控制已锁定`（橙黄 `#f59e0b`，暗黄底色 `#291e0a`）
    - 检测进行中：`🔄 自检中... (正在低速测试 M1/M2/M3 及霍尔编码器)`（天蓝 `#38bdf8`）
    - 自检全部通过：`✅ 自检通过 - 3轴硬件正常已解锁`（翡翠绿 `#34d399`，暗绿底色 `#064e3b`）
    - 存在故障：`❌ 自检失败 - 存在硬件异常，保持控制锁定`（暗红 `#f87171`，深红底色 `#450a0a`）
  - **操作按钮**：
    - `btn_self_test = QPushButton("🔍 开始硬件自检 (TEST)")`（高 32px，高亮工控按钮，自检中自动禁用防止重复触发）。
  - **3 轴明细状态网格**：
    - `M1 (TIM1/I2C1)`：`[待检测]` / `[正常 PASS]` / `[异常 FAIL]` | `通信率: -- | 旋转角: --`
    - `M2 (TIM3/I2C2)`：`[待检测]` / `[正常 PASS]` / `[异常 FAIL]` | `通信率: -- | 旋转角: --`
    - `M3 (TIM4/I2C3)`：`[待检测]` / `[正常 PASS]` / `[异常 FAIL]` | `通信率: -- | 旋转角: --`
  - **诊断提示栏**：动态显示自检进度或故障排查指引（如检查 I2C 上拉/电机连线/磁铁间距）。

### 4. 严密的动作拦截与控制互锁机制
- **状态变量**：`self.self_test_passed = False`
- **控件级锁定 (`set_motor_controls_locked(True)`)**：
  - 锁定：M1/M2/M3 卡片的所有主动输入控件（转速滑条、SpinBox、使能勾选框、反转按钮、预设按钮）；
  - 锁定：三轴联动同步卡片（`sync_group`）；
  - 锁定：闭环与标定卡片（`cl_group`）；
  - 锁定：相电压上限/速度上限设定按钮；
  - 锁定：一键停止全部按钮（`btn_stop_all`）；
  - **例外放行**：【紧急停止 [ESTOP]】、串口打开/关闭、3D 姿态归零、清空日志始终保持有效可用；
  - **仪表数据显示不受影响**：锁定期间，角度、转速、IMU 与波形数据仍正常刷新显示。
- **终端指令级拦截 (`action_send_custom_cmd`)**：
  - 若用户在底部终端输入 `M ...`, `EN ...`, `MODE ...`, `ALIGN`, `PID ...` 等电机致动指令，且 `self_test_passed == False`，立即拦截并在终端和状态栏提示：“⚠️ 互锁保护：操作已拦截！必须先执行并通过硬件自检后方可控制电机。”

---

## 三、文件修改清单

1. **`无刷闭环联调/Core/Src/main.c`**：
   - 移除 `main()` 中上电调用的 `Motor_Encoder_OpenLoop_SelfTest()` 与开机 5 秒延时；
   - 在 `Motor_Encoder_OpenLoop_SelfTest()` 中输出结构化 `$TEST_STEP` 和 `$TEST_REPORT` 报文，并更新通过后的零位对齐逻辑；
   - 保持 `commander_run()` 对 `TEST`/`CHECK` 串口命令的响应。
2. **`无刷闭环联调/UpperComputer/main.py`**：
   - 在 `SerialWorker` 中增加 `$TEST_STEP` 和 `$TEST_REPORT` 的接收与信号发射；
   - 在 `MotorControlCard` 中增加 `set_operable(self, bool)` 方法；
   - 创建 `SelfTestCard` 控件类并整合到主窗口左面板顶部；
   - 实现 `set_motor_controls_locked(self, bool)` 互锁控制逻辑；
   - 在主窗口各动作函数和 `action_send_custom_cmd` 中实施互锁检测拦截；
   - 关联串口连接、断开、自检开始与自检结果事件。

---

## 四、验证方案

1. **固件编译验证**：
   - 使用 Keil MDK-ARM 5 命令行编译 `CubeMX.uvprojx`，确保 0 Error, 0 Warning，生成最新 `.hex`。
2. **上位机启动与互锁逻辑测试**：
   - 启动 Python 脚本 `python UpperComputer/main.py`，检查 UI 是否正常渲染 `SelfTestCard`；
   - 验证初始未自检状态下，电机滑条与使能控件是否被正确置灰锁定；
   - 验证终端输入 `M 5 0 0` 时是否被互锁成功拦截并给出醒目黄色警告；
   - 模拟自检指令下发与数据接收，验证各个状态徽章与结果展示是否符合预期。

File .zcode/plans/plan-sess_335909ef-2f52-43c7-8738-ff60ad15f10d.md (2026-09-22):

# 上位机修改与 3D 姿态立方体集成方案

## 1. 现状与问题定位

1. **无用 Emoji 清理**：
   - 移除现有界面中的所有 Emoji/特殊符号（如 `● 未连接`、`⚠ 紧急停止 (ESTOP)` 等），替换为简洁工控风格的文本指示（如 `[未连接]`、`[已连接]`、`[ESTOP 紧急停止]`）或 Qt 原生彩色状态圆点。
2. **电机转速曲线不显示的原因**：
   - **X 轴坐标系漂移**：`now = data['time'] - self.start_time` 采用绝对时间秒数，上位机未配置滚动时间窗（Rolling Window）；当用户无意拖动/点击图表后，pyqtgraph 会永久锁定当前视野在 `[0, 1]`，而实际数据已在数十秒开外，导致曲线跑出视口。
   - **全零数据重合与 Y 轴塌陷**：当三轴目标转速初始均为 0 时，三条细线完全重叠在 Y=0 的深色背景网格线上，且 Y 轴极值差为 0，若未锁定量程会导致画面看起来“空白无曲线”。
3. **三维立方体（3D Cubli Cube）技术选型**：
   - Python 3.14 环境中未安装 `PyOpenGL`，若强行引入 OpenGL 会面临驱动崩溃与缺少轮子的风险。
   - 采用 **基于 PyQt5 原生 `QPainter` 的高性能三维透视投影引擎**：零外部依赖，100% 保证在任意 Windows 系统上稳定以 60 FPS 流畅渲染；支持 3D 欧拉角/四元数旋转矩阵、面深度排序（画家算法）、光照着色、面文字标号（TOP / BOTTOM / M1 / M2 / M3）与鼠标拖拽视角。

---

## 2. 界面架构与布局重构

界面整体调整为直观清晰的左右结构：

```text
+----------------------------------------------------------------------------------------------------+
| 顶部操作栏: 串口选择 | 波特率 | 打开串口 [未连接/已连接] | 姿态归零 | 全部归零 | [ESTOP 紧急停止]    |
+---------------------------------------------------+------------------------------------------------+
| 左侧：调控面板 (约 420px)                         | 右侧：数据与 3D 监控面板 (约 860px)            |
| 1. 三轴电机独立控制面板 (M1/M2/M3)                | 1. 顶部：实时指标栏 (转速/角速度/姿态角/FPS)   |
|    - 滑条 + SpinBox (-30 ~ +30 rad/s)             | 2. 中部：上下分割布局                          |
|    - rad/s 与 RPM 双显                            |    - 上半部：3D 姿态立方体 (实时同步陀螺仪/加速度) |
|    - 驱动使能开关、快捷挡位、反转                 |    - 下半部：电机转速实时波形曲线 (平滑滚动显示)  |
| 2. 三轴同步联动 (Master / Sync)                   | 3. 底部：串口原始报文监视器与终端指令输入      |
| 3. 驱动相电压与速度限制 (Vq / Limit)              |                                                |
+---------------------------------------------------+------------------------------------------------+
| 状态栏: 当前连接状态、波特率、姿态解算刷新率                                                       |
+----------------------------------------------------------------------------------------------------+
```

---

## 3. 核心功能实现细节

### 3.1 电机转速曲线彻底修复与体验升级
- **引入示波器式动态滚动时间窗（Rolling Window）**：
  - 数据点采用固定滑动窗口（默认最近 10 秒）。
  - 在 `update_plots()` 中显式锁定 X 轴为 `[t_max - 10, t_max]`，并在 X 轴不足 10 秒时自动填充 `[0, 10]`，确保波形永远在可视区域内稳定向左平滑推进。
- **固化 Y 轴安全量程与防塌陷保护**：
  - 默认将 Y 轴量程设为 `[-25, +25] rad/s`，提供明显的虚线零位基准线。
  - 加粗曲线笔触（宽度 2.5px），M1（亮青）、M2（明橙）、M3（洋红）三色对比分明。
  - 无论电机处于静止（0 rad/s）还是动态调速，曲线均清晰可辨。

### 3.2 姿态解算引擎（IMU 互补滤波）
- **传感器数据源**：
  - 固件以 20Hz 实时上报 LSM6DSRTR 六轴数据：角速度 `Gx, Gy, Gz`（$^{\circ}/\text{s}$）与加速度 `Ax, Ay, Az`（$g$）。
- **默认姿态（水平朝上）**：
  - 静止水平放置时，$A_z \approx +1.0g$，$A_x \approx 0$，$A_y \approx 0$。
  - 加速度计静态姿态：
    $$\text{Pitch}_{acc} = \text{atan2}(A_x, \sqrt{A_y^2 + A_z^2}) \times \frac{180^\circ}{\pi}$$
    $$\text{Roll}_{acc} = \text{atan2}(A_y, A_z) \times \frac{180^\circ}{\pi}$$
- **互补滤波算法**：
  $$\text{Pitch} = 0.95 \times (\text{Pitch} + G_y \times \Delta t) + 0.05 \times \text{Pitch}_{acc}$$
  $$\text{Roll} = 0.95 \times (\text{Roll} + G_x \times \Delta t) + 0.05 \times \text{Roll}_{acc}$$
  $$\text{Yaw} = \text{Yaw} + G_z \times \Delta t$$
- 顶部增加 `[重置姿态]` 按钮，一键将当前静态角度置为初始水平参考零点。

### 3.3 3D Cubli 立方体组件 (`Cubli3DWidget`)
- **几何与物理对应**：
  - 构造三维立方体（8 顶点、6 面），长宽高严格等比。
  - **顶面 (Top, +Z)**：标有 `M3 (Top)`，对应电机 3。
  - **前侧面 (Front, +Y)**：标有 `M2 (Front)`，对应电机 2。
  - **右侧面 (Right, +X)**：标有 `M1 (Right)`，对应电机 1。
  - **底面 (Bottom, -Z)**：触地接触角/面。
- **渲染特效**：
  - **3D 透视投影**：随视距产生自然的近大远小透视感。
  - **面明暗光照**：根据面法向量与平行光夹角动态调整面颜色明暗度。
  - **三维坐标轴**：在立方体中心绘制 X(红)/Y(绿)/Z(蓝) 空间指向箭头。
  - **地面投影与阴影**：在下方绘制轻量化地面网格，强化空间姿态感。
  - **飞轮旋转动量轮动画**：在各面上绘制飞轮圆盘，随着各轴电机的实际转速动态旋转。
  - **交互支持**：支持鼠标左键拖拽调整观察者视角，双击恢复默认正等侧视角。

### 3.4 界面无用 Emoji 清除
- 将所有 `●`、`⚠` 等特殊符号替换为规范的标准文本与 CSS 颜色标签。

---

## 4. 实施步骤

1. **编写 3D 立方体组件**：在 `UpperComputer/main.py` 中实现 `Cubli3DWidget(QWidget)`，包含姿态矩阵计算、透视投影与 QPainter 面绘制逻辑。
2. **重构主界面布局**：
   - 左侧保留电机调控、参数设置面板。
   - 右侧上方放置 3D 姿态立方体，下方放置电机转速实时曲线及原始串口终端。
3. **修复电机转速曲线**：
   - 改为固定 10 秒滚动时间窗，修复 autoRange 导致的数据出界问题。
   - 设置稳固的默认量程和高辨识度绘图样式。
4. **清理 Emoji 符号**：
   - 替换状态灯、急停按钮及日志输出中的所有 Emoji。
5. **测试验证**：
   - 运行无界面组件与逻辑测试脚本，验证姿态计算、波形滚动与控件生命周期。
   - 启动测试上位机，确认画面表现与流畅度。

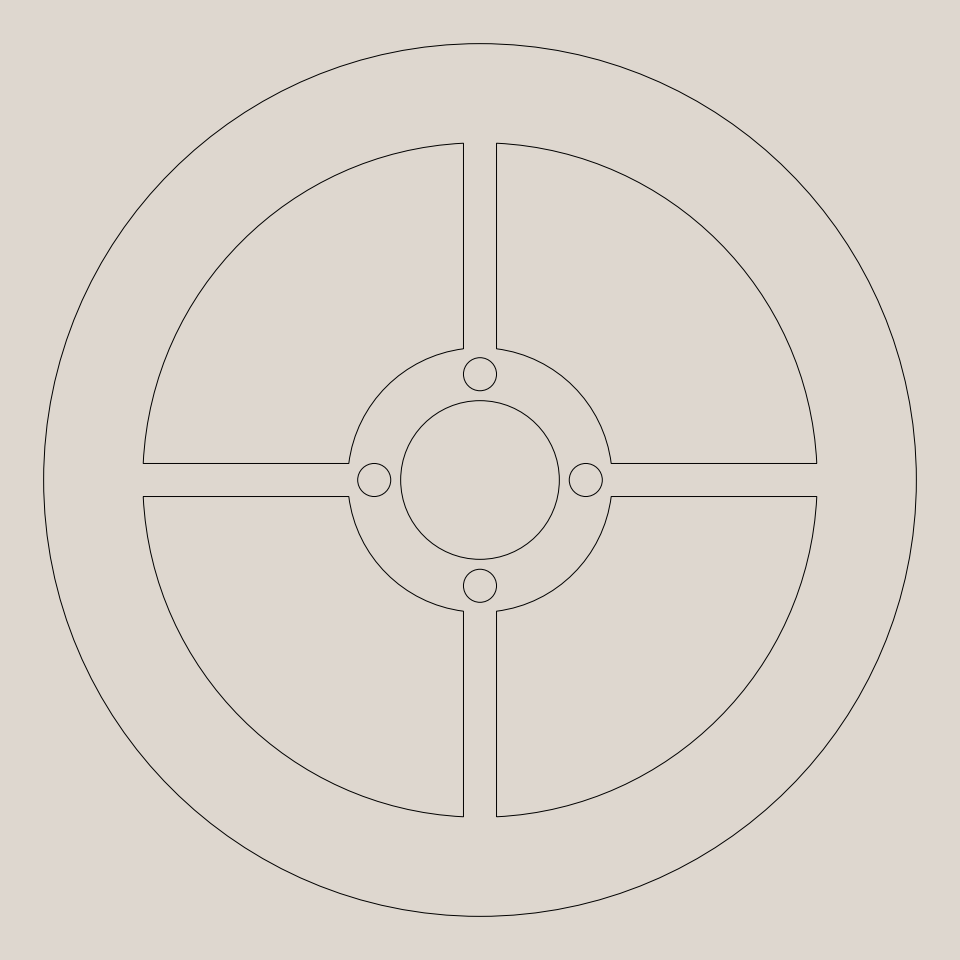
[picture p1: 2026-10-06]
Mechanical/2D/动量轮CAD.png

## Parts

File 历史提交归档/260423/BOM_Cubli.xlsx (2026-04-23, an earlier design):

No. | Quantity | Comment | Designator | Footprint | Value | Manufacturer Part | Manufacturer | Supplier Part | Supplier
45 | 4 | 0 | R53,R54,R55,R56 | R0402 | 0
34 | 1 | 0.5 | R28 | R0402 | 0.5
33 | 3 | 10 | R20,R23,R26 | R0402 | 10
32 | 5 | 100 | R19,R22,R25,R51,R52 | R0402 | 100
1 | 55 | 100nF | C1,C2,C4,C6,C7,C9,C11,C12,C14,C17,C18,C19,C20,C21,C22,C23,C24,C25,C26,C27,C28,C37,C39,C40,C41,C42,C43,C44,C45,C46,C47,C48,C49,C50,C51,C52,C53,C54,C55,C56,C57,C58,C61,C62,C63,C67,C72,C73,C74,C75,C77,C78,C79,C80,C81 | C0402 | 100nF
21 | 12 | 10K | NTC,NTC1,NTC2,NTC3,R41,R47,R48,R49,R50,R57,R58,R60 | R0402 | 10K
29 | 1 | 10M | R7 | R0402 | 10M
30 | 2 | 10m | R8,R9 | R1206 | 10m
2 | 3 | 10nF | C3,C8,C13 | C0402 | 10nF
10 | 4 | 10pF | C68,C69,C70,C71 | C0402 | 10pF
3 | 3 | 10uF | C5,C10,C15 | C_Ele_SMD_3x5.4mm | 10uF
4 | 6 | 10uF | C16,C29,C30,C31,C32,C35 | C0402 | 10uF
5 | 2 | 10uF | C33,C34 | C0603 | 10uF
41 | 1 | 14.7K | R39 | R0402 | 14.7K
25 | 11 | 1K | R3,R10,R13,R16,R21,R24,R27,R29,R30,R32,R43 | R0402 | 1K
24 | 5 | 1m | R1,R2,R12,R15,R18 | R0402 | 1m
13 | 1 | 1N5819WS | D1 | SOD-323_L1.8-W1.3-LS2.5-RD |  | 1N5819WS | Hottech(合科泰) | C191023 | LCSC
9 | 3 | 2.2nF | C64,C65,C66 | C0402 | 2.2nF
8 | 2 | 2.2uF | C59,C60 | C0402 | 2.2uF
17 | 1 | 2.2uH | L1 | IND-SMD_L6.0-W6.0_SWPA6045S | 2.2uH | SWPA6045S2R2NT | Sunlord(顺络) | C36500 | LCSC
18 | 1 | 2.2uH | L2 | IND-SMD_L2.0-W1.6 | 2.2uH
44 | 3 | 220Ω | R44,R45,R46 | R0402 | 220Ω | PTFR0402B220RP9 | RESI(开步睿思) | C478868 | LCSC
62 | 1 | 25MHz | X2 | CRYSTAL-SMD_4P-L3.2-W2.5-BL | 25MHz | X322525MOB4SI | YXC(扬兴晶振) | C9006 | LCSC
28 | 2 | 2K | R6,R59 | R0402 | 2K
61 | 1 | 32.768kHz | X1 | CRYSTAL-SMD_L3.2-W1.5-1 | 32.768kHz | XKXGI-SUA-32.768K | YXC(扬兴晶振) | C5213671 | LCSC
40 | 1 | 4.7K | R38 | R0402 | 4.7K
27 | 1 | 47K | R5 | R0402 | 47K
31 | 3 | 47R | R11,R14,R17 | R0402 | 47R
6 | 1 | 47uF | C36 | C0805 | 47uF
7 | 1 | 47uF | C38 | C0402 | 47uF
42 | 1 | 49.9K | R40 | R0402 | 49.9K
37 | 2 | 5.1K | R34,R35 | R0402 | 5.1K
38 | 1 | 50kΩ | R36 | RES-ADJ-SMD_VG039NCH | 50kΩ | VG039NCHXTB503 | HDK(北陆电气) | C145161 | LCSC
39 | 2 | 51K | R37,RNTC | R0402 | 51K
26 | 1 | 6.2K | R4 | R0402 | 6.2K
35 | 2 | 68K | R31,RVST | R0402 | 68K
36 | 1 | 75K | R33 | R0402 | 75K
22 | 6 | AO3400 | Q1,Q2,Q3,Q4,Q5,Q6 | SOT-23_L2.9-W1.3-P1.90-LS2.4-BR |  | AO3400 | GOODWORK(固得沃克) | C2938367 | LCSC
56 | 1 | BAT54C | U15 | SOT-23-3_L2.9-W1.3-P1.90-LS2.8-BR |  | BAT54C | R+O(宏嘉诚) | C22466350 | LCSC
50 | 1 | BM3451UNDC-T28A | U4 | TSSOP-28_L9.7-W4.4-P0.65-LS6.4-BL |  | BM3451UNDC-T28A |  | C94597 | LCSC
15 | 1 | BZT52C16 | D3 | SOD-123_L2.7-W1.6-LS3.7-RD |  | BZT52C16 | R+O(宏嘉诚) | C19077413 | LCSC
49 | 3 | DRV8313PWPR | U1,U2,U3 | HTSSOP-28_L9.8-W4.5-P0.65-LS6.6-BL-EP |  | DRV8313PWPR | TI(德州仪器) | C92482 | LCSC
19 | 1 | GZ1608D601TF 600Ω@100MHz | L3 | L0603 |  | GZ1608D601TF 600Ω@100MHz | Sunlord(顺络) | C1002 | LCSC
16 | 1 | HDR-F_2.54_2x4 | H1 | HDR-TH_8P-P2.54-V-F-R2-C4-S2.54-1 |  |  |  | C92271
12 | 1 | HX25003-4AWB | CN2 | CONN-SMD_4P-P2.50_HX25003-4AWB |  | HX25003-4AWB | HX(红星) | C442363 | LCSC
23 | 1 | HY19P03D | Q7 | TO-252-2_L6.6-W6.1-P4.57-LS9.9-TL-CW |  | HY19P03D | HUAYI(华羿微) | C122492 | LCSC
52 | 3 | HY2213-BB3A | U9,U10,U11 | SOT-23-6_L2.9-W1.6-P0.95-LS2.8-BR |  | HY2213-BB3A | HYCON(宏康) | C113632 | LCSC
53 | 1 | IP2326 | U12 | VQFN-24_L4.0-W4.0-P0.50-BL-EP2.5 |  | IP2326 | INJOINIC(英集芯) | C2832094 | LCSC
20 | 6 | LED_0603-R | LED1,LED2,LED3,LED4,LED5,LED6 | LED_0402
57 | 1 | LSM6DSRTR | U16 | LGA-14_L3.0-W2.5-P0.50-BR |  | LSM6DSRTR | ST(意法半导体) | C784817 | LCSC
58 | 1 | MPU-6050 | U17 | QFN-24_L4.0-W4.0-P0.50-BL-EP2.7 |  | MPU-6050 | TDK InvenSense(应美盛) | C24112 | LCSC
43 | 1 | NC | R42 | R0402 | NC
14 | 1 | PESD3V3L1BA | D2 | SOD-323_L1.7-W1.3-LS2.5-BI |  | PESD3V3L1BA | TECH PUBLIC(台舟) | C2827682 | LCSC
46 | 1 | SK-3296S-01-L1 | SW1 | SW-SMD_3P-P1.50_L2.7-W6.6 |  | SK-3296S-01-L1 | XKB Connection(中国星坤) | C319020 | LCSC
48 | 1 | SS12D10G4 071 | SW3 | SW-TH_SHOU-HAN_SS12D10G4 |  | SS12D10G4 071 | SHOU HAN(首韩) | C2887259 | LCSC
55 | 1 | STM32F407ZGT6 | U14 | LQFP-144_L20.0-W20.0-P0.50-LS22.0-BL |  | STM32F407ZGT6 | ST(意法半导体) | C19156 | LCSC
51 | 4 | TPN2R703NL | U5,U6,U7,U8 | TSON-8_L3.1-W3.1-P0.65-LS3.3-BL-EP |  | TPN2R703NL |  | C2939631 | LCSC
54 | 1 | TPS565201DDCR | U13 | SOT-23-6_L2.9-W1.6-P0.95-LS2.8-BR |  | TPS565201DDCR | TI(德州仪器) | C327676 | LCSC
47 | 1 | TS-1088-AR02016 | SW2 | SW-SMD_L3.9-W3.0-P4.45 |  | TS-1088-AR02016 | XUNPU(讯普) | C720477 | LCSC
60 | 1 | TYPE-C16PIN | USB1 | USB-C-SMD_TYPE-C16PIN |  | TYPE-C16PIN | SHOU HAN(首韩) | C393939 | LCSC
11 | 1 | XT30PW-M30.G.Y | CN1 | CONN-TH_XT30PW-M |  | XT30PW-M30.G.Y | AMASS(艾迈斯) | C431092 | LCSC
59 | 3 | ZX-SH1.0-4PWT | U18,U19,U20 | CONN-SMD_4P-P1.00_MEGASTAR_ZX-SH1.0-4PWT |  | ZX-SH1.0-4PWT | Megastar(兆星) | C7430446 | LCSC

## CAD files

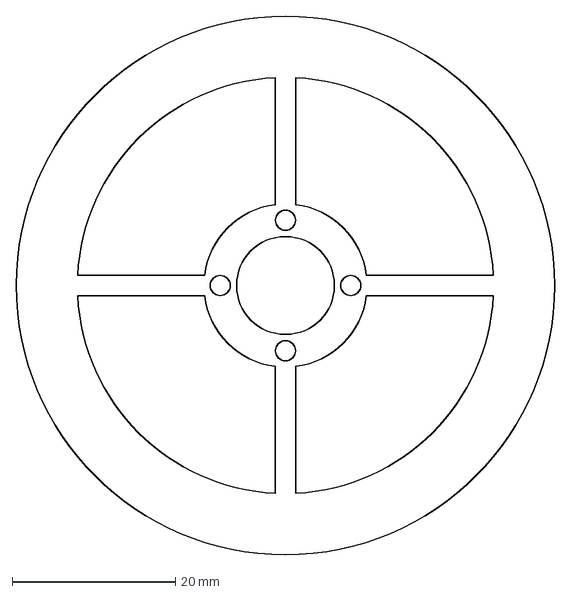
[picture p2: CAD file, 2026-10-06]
Mechanical/2D/动量轮CAD.dxf
66.0 x 66.0 mm

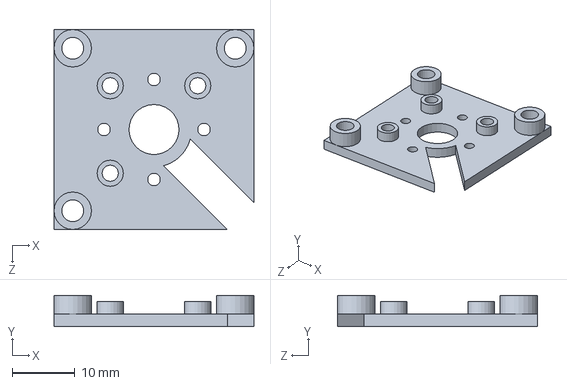
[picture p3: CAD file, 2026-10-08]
Mechanical/3D/无刷霍尔底座.SLDPRT
32.0 x 5.00 x 32.0 mm

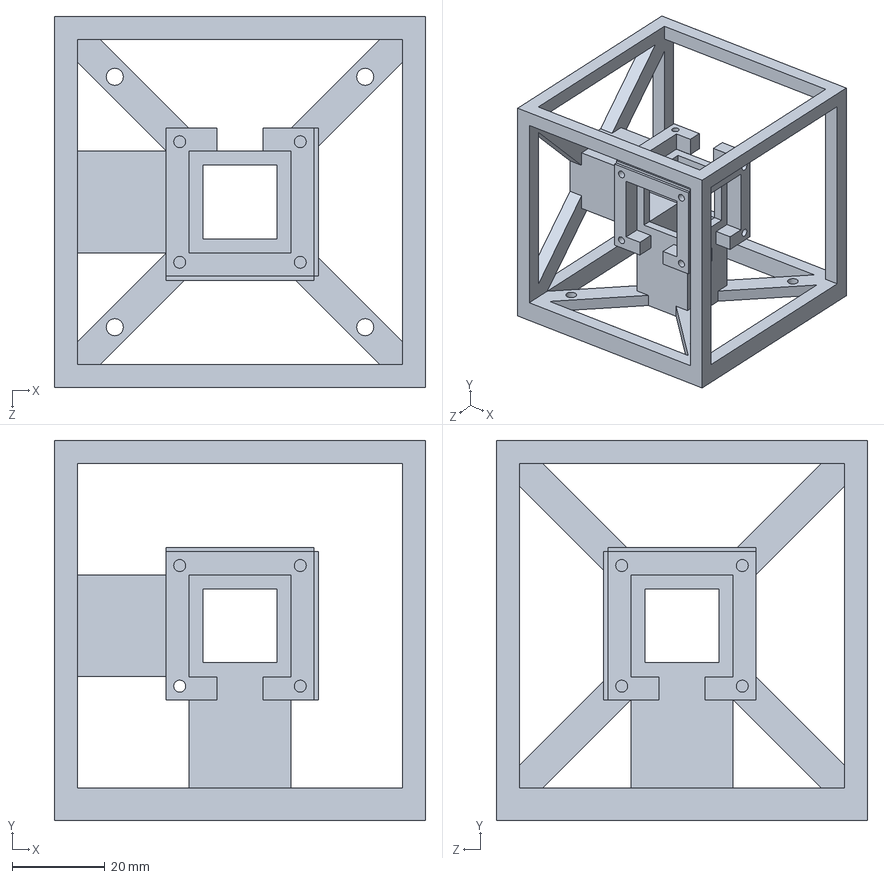
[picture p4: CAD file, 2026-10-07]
Mechanical/3D/主框架.SLDPRT
80.0 x 82.0 x 80.0 mm

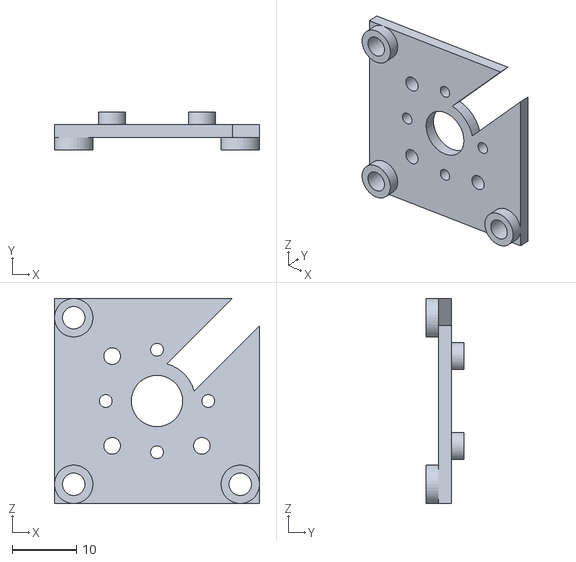
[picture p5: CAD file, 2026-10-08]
Mechanical/STL/无刷霍尔底座-261008-2119.STL
32.0 x 6.00 x 32.0

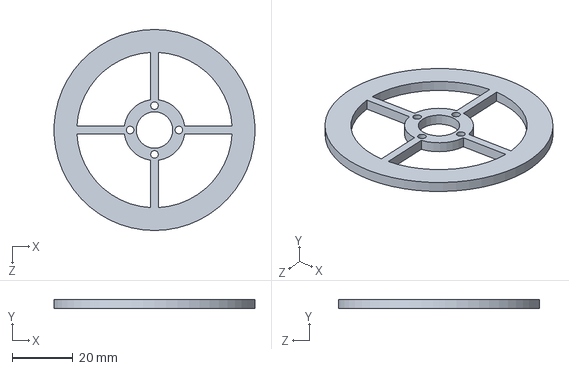
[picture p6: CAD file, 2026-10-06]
Mechanical/3D/动量轮.SLDPRT
66.0 x 3.00 x 66.0 mm

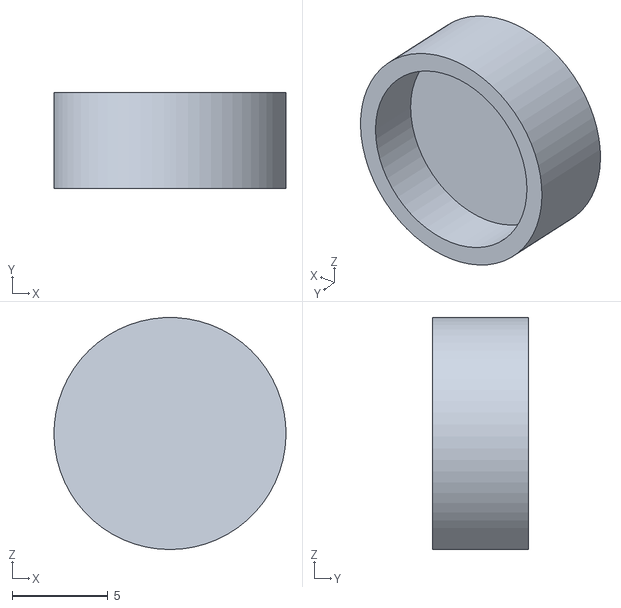
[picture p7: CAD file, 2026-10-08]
Mechanical/STL/动量轮限位器-261008-2106.STL
12.1 x 5.00 x 12.1

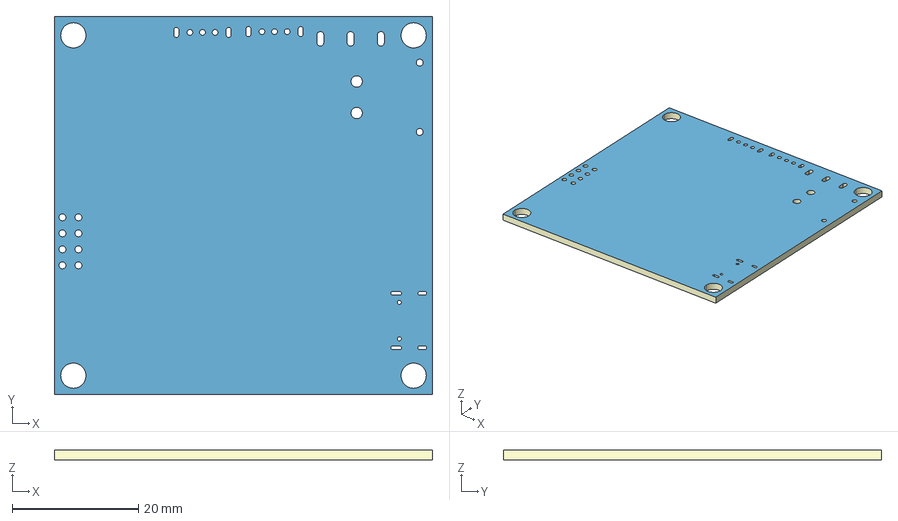
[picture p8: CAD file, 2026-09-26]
Mechanical/3D/3D_MBO_2026-09-26.step
60.0 x 60.0 x 1.54 mm
Board~8QTj
TopCopper~8QTj
BottomCopper~8QTj
TopFpcStiffener~8QTj
BottomFpcStiffener~8QTj

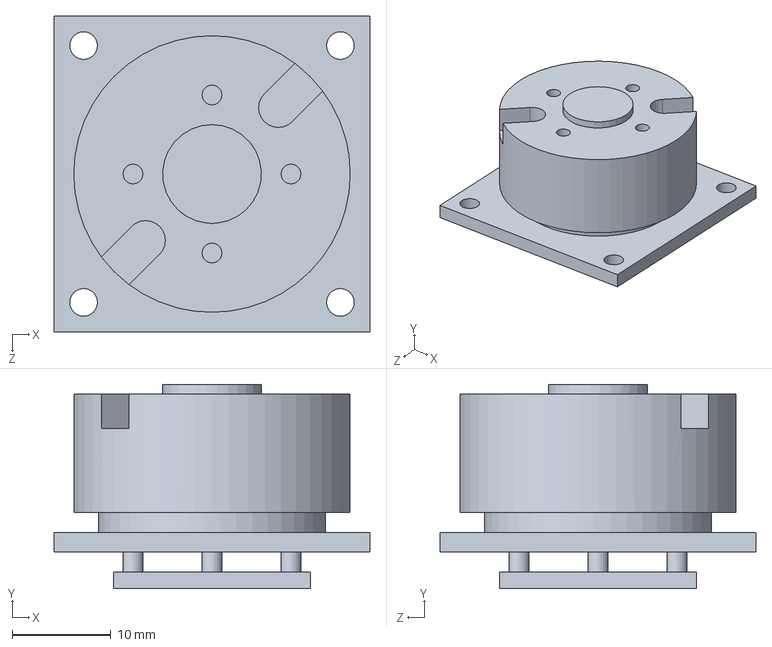
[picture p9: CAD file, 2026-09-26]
Mechanical/3D/2804无刷.SLDPRT
32.0 x 20.7 x 32.0 mm

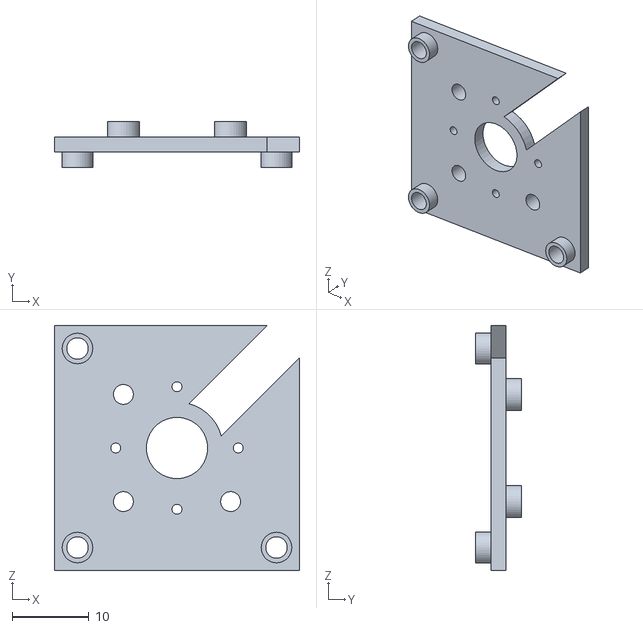
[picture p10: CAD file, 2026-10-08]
Mechanical/STL/无刷霍尔底座-261008-2051.STL
32.0 x 6.00 x 32.0

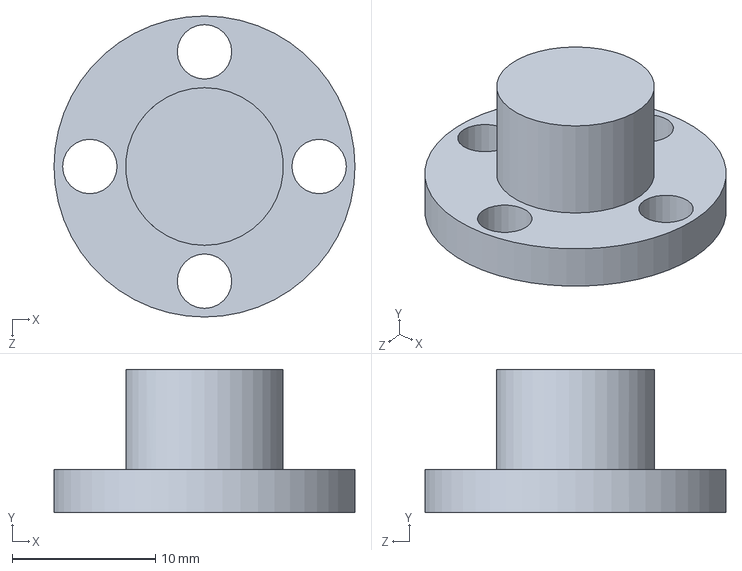
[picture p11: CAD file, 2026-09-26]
Mechanical/3D/动量轮法兰.SLDPRT
21.0 x 10.0 x 21.0 mm

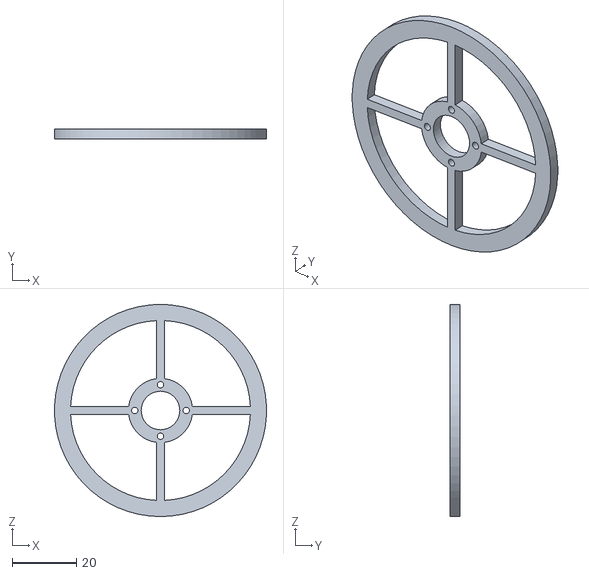
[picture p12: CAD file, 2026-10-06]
Mechanical/STL/动量轮-260927-1833.STL
66.0 x 3.00 x 66.0

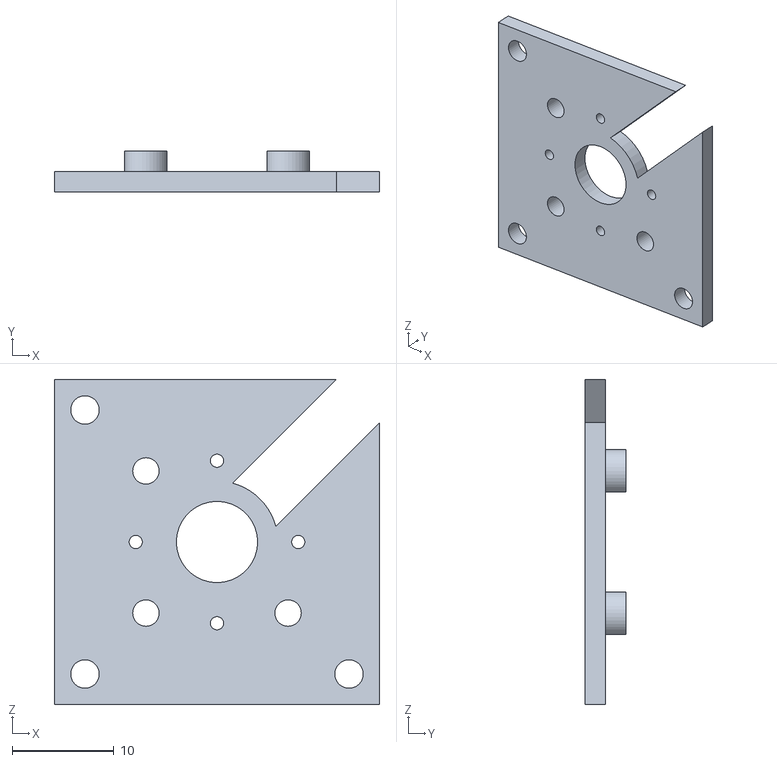
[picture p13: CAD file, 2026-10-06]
Mechanical/STL/无刷霍尔底座-260927-1832.STL
32.0 x 4.00 x 32.0

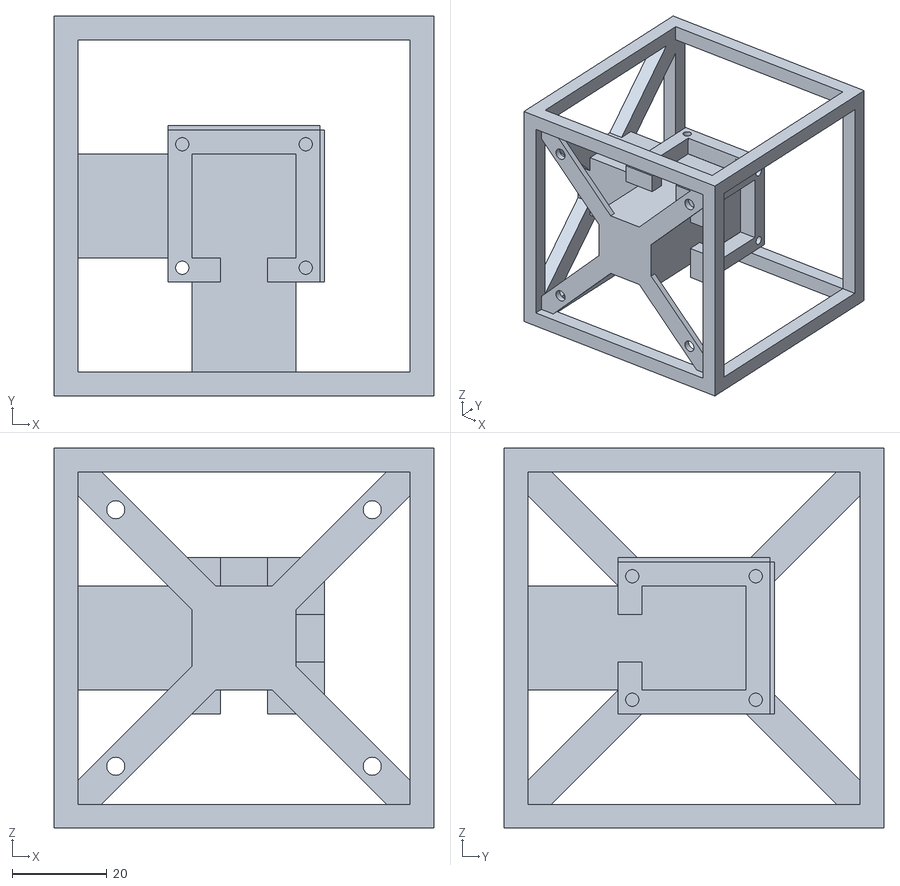
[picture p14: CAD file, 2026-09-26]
Mechanical/STL/主框架-260926-1936.STL
80.0 x 80.0 x 80.0

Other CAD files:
Mechanical/STL/无刷霍尔底座-261008-2200.STL
Mechanical/STL/动量轮限位器.SLDPRT
Mechanical/STL/主框架-261007-1904.STL
Mechanical/STL/动量轮-261006-1415.STL
Mechanical/STL/主框架-261002-0303.STL
Mechanical/2D/动量轮CAD.dwg
Mechanical/STL/动量轮.STL
Mechanical/STL/无刷霍尔底座-260926-1935.STL
Mechanical/STL/无刷霍尔底座.STL

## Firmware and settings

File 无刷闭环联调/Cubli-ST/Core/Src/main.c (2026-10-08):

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
/* Includes ------------------------------------------------------------------*/
#include "main.h"
#include "i2c.h"
#include "tim.h"
#include "usart.h"
#include "gpio.h"

/* USER CODE BEGIN Includes */
#include <stdio.h>
#include <stdlib.h>
#include "MyProject.h"
/* USER CODE END Includes */


/* USER CODE BEGIN PV */
float target = 0.0f;       // SimpleFOC global target (sets all motors)
float target_m1 = 0.0f;    // M1 individual target
float target_m2 = 0.0f;    // M2 individual target
float target_m3 = 0.0f;    // M3 individual target
uint8_t m1_enabled = 1;    // M1 驱动使能标志
uint8_t m2_enabled = 1;    // M2 驱动使能标志
uint8_t m3_enabled = 1;    // M3 驱动使能标志
uint8_t telemetry_enabled = 1; // 周期遥测上报开关 (默认开启)
uint32_t tele_counter = 0; // 遥测计时分频计数器

/* 陀螺仪与加速度计数据缓存 */
float imu_accel[3] = {0.0f, 0.0f, 0.0f}; // 单位: g
float imu_gyro[3]  = {0.0f, 0.0f, 0.0f}; // 单位: °/s (dps)
uint8_t imu_online = 0;                  // 传感器在线状态 (1: 在线, 0: 离线)
uint8_t imu_active_type = ACTIVE_IMU;    // 1: LSM6DSRTR, 2: MPU6050

/* 三轴霍尔/磁编码角度读数 (MT6701-1, MT6701-2, MT6701-3) 为闭环做准备 */
int16_t hall_raw[3] = {0, 0, 0};         // 原始 14-bit 数值 (0 ~ 16383)
float hall_angle_deg[3] = {0.0f, 0.0f, 0.0f}; // 角度 (0.00 ~ 359.99°)
uint8_t hall_online[3] = {0, 0, 0};      // 传感器在线标志 (1: 正常, 0: 离线)
/* USER CODE END PV */

void SystemClock_Config(void);
/* USER CODE BEGIN PFP */
void commander_run(void);
void set_motor_enable(uint8_t motor, uint8_t en);
void Boot_PG4_Blink_5s(void);
void Motor_Encoder_OpenLoop_SelfTest(void);
void Motor_Measure_PolePairs(uint8_t motor);
/* USER CODE END PFP */

/**
  * @brief  The application entry point.
  * @retval int
  */
int main(void)
{

  /* MCU Configuration--------------------------------------------------------*/

  /* Reset of all peripherals, Initializes the Flash interface and the Systick. */
  HAL_Init();

  /* Configure the system clock */
  SystemClock_Config();

  /* Initialize all configured peripherals */
  MX_GPIO_Init();
  MX_USART2_UART_Init();
  MX_USART1_UART_Init();   /* 板载 ESP32-WROOM32E 无线上位机链路 (PA9/PA10) */
  MX_I2C2_Init();
  MX_I2C1_Init();
  MX_I2C3_Init();
  MX_TIM3_Init();
  MX_TIM4_Init();
  MX_TIM1_Init();
  /* USER CODE BEGIN 2 */
	printf("\r\n--- STM32F407 System Clock: %ld Hz ---\r\n", HAL_RCC_GetHCLKFreq());
	printf("--- APB1 Timer Clock: %ld Hz ---\r\n", HAL_RCC_GetPCLK1Freq() * 2);
	printf("--- APB2 Timer Clock: %ld Hz ---\r\n", HAL_RCC_GetPCLK2Freq() * 2);

		/* 硬件安全配置检查(确保PD0/PD1/PD2被正确配置为推挽输出) */
		Motor_GPIO_Safety_Check();

		/* 初始化TIM5 32位全硬件微秒定时器与TIM6 1ms时基 */
		TIM5_Micros_Init();
		TIM6_1ms_Init();           // 1ms定时器中断

		/* 上电快速指示 (PG4亮200ms后熄灭，避免开机长时间阻塞，静候上位机指令) */
		HAL_GPIO_WritePin(GPIOG, GPIO_PIN_4, GPIO_PIN_SET);
		delay_ms(200);
		HAL_GPIO_WritePin(GPIOG, GPIO_PIN_4, GPIO_PIN_RESET);

				/* SimpleFOC参数配置 */
				voltage_power_supply = 12.0f;   // V (DRV8313 12V 硬件供电)
				voltage_limit = 5.0f;           // V (动态相电压上限设为 5.0V，兼顾急速启停力矩与电气安全)
				velocity_limit = 60.0f;         // rad/s (最高转速提升至 60.0 rad/s)
				controller = Type_velocity_openloop; // 默认开环安全待机，避免未标定零位时闭环自激扰动
			pole_pairs = 7;                 // 极对数

					SimpleFOC_PID_Init();           // 初始化速度闭环 PID 与低通滤波器
					LQR_Balance_Init();             // 初始化 Cubli 反作用飞轮 LQR 平衡控制器
					reset_closed_loop_state(-1);    // 初始化闭环同步电角度与控制时间戳
				set_motor_enable(0, 0);         // 上电默认失能三路电机，等待上位机自检指令解锁
			printf("3 motors initialized and IDLE (Safe Lock Mode).\r\n");

	/* 初始化陀螺仪/IMU */
	if (imu_active_type == IMU_TYPE_LSM6DSR)
	{
		printf("Init LSM6DSRTR on SPI2 (PB12=CS, PB13=SCK, PB14=MISO, PB15=MOSI)...\r\n");
		if (LSM6DSR_Init() == 0)
		{
			imu_online = 1;
			printf("LSM6DSRTR ready! WHO_AM_I=0x%02X\r\n", LSM6DSR_Read_ID());
		}
		else
		{
			imu_online = 0;
			printf("LSM6DSRTR init failed or not responding (WHO_AM_I=0x%02X)\r\n", LSM6DSR_Read_ID());
		}
	}
	else if (imu_active_type == IMU_TYPE_MPU6050)
	{
		printf("Init MPU-6050 on soft I2C (PB10=SCL, PB11=SDA)...\r\n");
		if (MPU6050_Init() == 0)
		{
			imu_online = 1;
			printf("MPU-6050 ready! WHO_AM_I=0x%02X\r\n", MPU6050_Read_ID());
		}
		else
		{
			imu_online = 0;
			printf("MPU-6050 init failed (WHO_AM_I=0x%02X)\r\n", MPU6050_Read_ID());
		}
	}

		/* MT6701 磁编码器上电自检
		 * 编码器读取方式由编译期宏 ENC_USE_HW_QUAD 决定 (enc_quad.h):
		 *   0 = 三路 I2C 绝对式读取 (原方法, 默认)
		 *   1 = TIM2/TIM5/TIM8 硬件正交解码 (新方法, ABZ 增量输出, 需先初始化定时器)
		 */
#if ENC_USE_HW_QUAD
		ENC_Quad_Init();
		printf("Encoder mode: HW Quadrature (TIM2=M1 PA5/PB3, TIM5=M2 PA0/PA1, TIM8=M3 PC6/PC7), %d counts/rev\r\n", ENC_QUAD_COUNTS_PER_REV);
#else
		printf("Encoder mode: I2C absolute (I2C1 PB6/PB7, I2C2 PF1/PF0, I2C3 PA8/PC9)\r\n");
#endif
		hall_online[0] = (ENC_GetAngle(0, &hall_raw[0], &hall_angle_deg[0]) == 0);
		hall_online[1] = (ENC_GetAngle(1, &hall_raw[1], &hall_angle_deg[1]) == 0);
		hall_online[2] = (ENC_GetAngle(2, &hall_raw[2], &hall_angle_deg[2]) == 0);
		printf("MT6701: M1=%s(%.1f deg), M2=%s(%.1f deg), M3=%s(%.1f deg)\r\n",
			hall_online[0] ? "ONLINE" : "OFFLINE", hall_angle_deg[0],
			hall_online[1] ? "ONLINE" : "OFFLINE", hall_angle_deg[1],
			hall_online[2] ? "ONLINE" : "OFFLINE", hall_angle_deg[2]);

				/* 启动TIM3/TIM4 PWM输出 (TIM1在MX_TIM1_Init后由Motor_GPIO_Safety_Check使能) */
				HAL_TIM_PWM_Start(&htim3, TIM_CHANNEL_1);
				HAL_TIM_PWM_Start(&htim3, TIM_CHANNEL_2);
				HAL_TIM_PWM_Start(&htim3, TIM_CHANNEL_3);
				HAL_TIM_PWM_Start(&htim4, TIM_CHANNEL_1);
				HAL_TIM_PWM_Start(&htim4, TIM_CHANNEL_2);
				HAL_TIM_PWM_Start(&htim4, TIM_CHANNEL_3);

				/* 上电默认保持静止与SysTick微秒时基，不自动执行电机开环自检，等待上位机下发 TEST 检测指令 */
				systick_CountMode();
				printf("System initialized. Motors idle, waiting for UpperComputer Self-Test (TEST)...\r\n");

			target = 0.0f;                  // 上电初始保持静止，等待上位机或终端设定
		target_m1 = target;
		target_m2 = target;
		target_m3 = target;
  /* USER CODE END 2 */

	  /* Infinite loop */
	  /* USER CODE BEGIN WHILE */
		static uint32_t last_bal_tick = 0;

		while(1)
		{
				/* 5ms (200Hz) 高频平衡与姿态控制任务: IMU数据采集、卡尔曼滤波姿态解算与LQR控制循环 */
				uint32_t cur_tick = HAL_GetTick();
				if((cur_tick - last_bal_tick) >= 5)
				{
					float dt_bal = (float)(cur_tick - last_bal_tick) * 0.001f;
					last_bal_tick = cur_tick;

					/* 读取六轴 IMU 数据 */
					if (imu_online)
					{
						if (imu_active_type == IMU_TYPE_LSM6DSR)
						{
							LSM6DSR_Get_Data(imu_accel, imu_gyro);
						}
						else if (imu_active_type == IMU_TYPE_MPU6050)
						{
							MPU6050_Get_Data(imu_accel, imu_gyro);
						}

						/* 卡尔曼滤波更新机体倾角与角速度 */
						LQR_Attitude_Update(imu_accel, imu_gyro, dt_bal);
					}

					/* 执行 LQR 状态反馈平衡控制计算 (仅在平衡激活或校准时接管电机) */
					if(cubli_bal.state != BAL_STATE_DISABLED)
					{
						LQR_Balance_Loop();
					}
				}

				/* 40ms (25Hz) 周期任务：遥测上报与工作指示 (降低串口阻塞比重，保障FOC高频连续换向) */
				if(time1_cntr >= 40)
				{
					time1_cntr = 0;
					tele_counter++;

					/* 依据动态映射表获取每个电机对应的编码器实时机械角度 (直接读取FOC核心更新的角度，避免总线重复阻塞) */
					float m_angle_deg[3];
					m_angle_deg[0] = angle_prev[0] * 180.0f / _PI;
					m_angle_deg[1] = angle_prev[1] * 180.0f / _PI;
					m_angle_deg[2] = angle_prev[2] * 180.0f / _PI;

						if(telemetry_enabled)
						{
							/* 扩展标准化遥测格式 (包含三电机目标速度、相电压、使能状态、电角度、六轴陀螺仪加速度、通道映射后MT6701角度H1/H2/H3、实测滤波转速S1/S2/S3、解算Pitch/Roll姿态角及平衡状态Bal) */
							printf("$TELE,M1:%.2f,M2:%.2f,M3:%.2f,Vq:%.2f,EN:%d%d%d,A1:%.2f,A2:%.2f,A3:%.2f,Gx:%.1f,Gy:%.1f,Gz:%.1f,Ax:%.2f,Ay:%.2f,Az:%.2f,H1:%.1f,H2:%.1f,H3:%.1f,S1:%.2f,S2:%.2f,S3:%.2f,Pit:%.2f,Rol:%.2f,Bal:%d#\r\n",
								target_m1, target_m2, target_m3,
								voltage_limit,
								m1_enabled, m2_enabled, m3_enabled,
								shaft_angle[0], shaft_angle[1], shaft_angle[2],
								imu_gyro[0], imu_gyro[1], imu_gyro[2],
								imu_accel[0], imu_accel[1], imu_accel[2],
								m_angle_deg[0], m_angle_deg[1], m_angle_deg[2],
								shaft_velocity[0], shaft_velocity[1], shaft_velocity[2],
								cubli_bal.attitude.pitch_deg, cubli_bal.attitude.roll_deg, cubli_bal.state);
						}

				/* 200ms (5次) 翻转LED指示灯: PG0对应M1, PG1对应M2, PG2对应M3 */
				if((tele_counter % 5) == 0)
				{
					if(m1_enabled) HAL_GPIO_TogglePin(GPIOG, GPIO_PIN_0);
					else HAL_GPIO_WritePin(GPIOG, GPIO_PIN_0, GPIO_PIN_RESET);

					if(m2_enabled) HAL_GPIO_TogglePin(GPIOG, GPIO_PIN_1);
					else HAL_GPIO_WritePin(GPIOG, GPIO_PIN_1, GPIO_PIN_RESET);

					if(m3_enabled) HAL_GPIO_TogglePin(GPIOG, GPIO_PIN_2);
					else HAL_GPIO_WritePin(GPIOG, GPIO_PIN_2, GPIO_PIN_RESET);
				}

				/* 1000ms (25次) 输出控制台可读格式(仅在关闭TELE时输出) */
				if(tele_counter >= 25)
				{
					tele_counter = 0;
					if(!telemetry_enabled)
					{
						printf("M1:%.3f[%lu %lu %lu]  M2:%.3f[%lu %lu %lu]  M3:%.3f[%lu %lu %lu]  Vq=%.2f\r\n",
							shaft_angle[0],
							TIM1->CCR1, TIM1->CCR2, TIM1->CCR3,
							shaft_angle[1],
							TIM3->CCR1, TIM3->CCR2, TIM3->CCR3,
							shaft_angle[2],
							TIM4->CCR1, TIM4->CCR2, TIM4->CCR3,
							voltage_limit);
					}
				}
			}

			/* 无刷电机驱动输出: 平衡失能状态下执行常规速度控制; 平衡开启时由 LQR_Balance_Loop 接管相电压 */
			if(cubli_bal.state == BAL_STATE_DISABLED)
			{
				if(m1_enabled) move(target_m1, 0); else { TIM1->CCR1 = 0; TIM1->CCR2 = 0; TIM1->CCR3 = 0; }
				if(m2_enabled) move(target_m2, 1); else { TIM3->CCR1 = 0; TIM3->CCR2 = 0; TIM3->CCR3 = 0; }
				if(m3_enabled) move(target_m3, 2); else { TIM4->CCR1 = 0; TIM4->CCR2 = 0; TIM4->CCR3 = 0; }
			}

		/* 串口命令解析处理 */
		commander_run();
	}

    /* USER CODE END WHILE */

}

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
/* USER CODE BEGIN 4 */
/******************************************************************************/
/* 控制三路电机 DRV8313 驱动使能状态 (motor: 0=全部, 1=M1, 2=M2, 3=M3) */
void set_motor_enable(uint8_t motor, uint8_t en)
{
	if(motor == 0 || motor == 1)
	{
		m1_enabled = en ? 1 : 0;
		if(m1_enabled) { reset_closed_loop_state(0); M1_Enable; }
		else { M1_Disable; TIM1->CCR1 = 0; TIM1->CCR2 = 0; TIM1->CCR3 = 0; }
	}
	if(motor == 0 || motor == 2)
	{
		m2_enabled = en ? 1 : 0;
		if(m2_enabled) { reset_closed_loop_state(1); M2_Enable; }
		else { M2_Disable; TIM3->CCR1 = 0; TIM3->CCR2 = 0; TIM3->CCR3 = 0; }
	}
	if(motor == 0 || motor == 3)
	{
		m3_enabled = en ? 1 : 0;
		if(m3_enabled) { reset_closed_loop_state(2); M3_Enable; }
		else { M3_Disable; TIM4->CCR1 = 0; TIM4->CCR2 = 0; TIM4->CCR3 = 0; }
	}
}

/******************************************************************************/
/* 串口控制指令解析引擎 */
void commander_run(void)
{
	if((USART_RX_STA & 0x8000) != 0)
	{
		char *cmd = (char *)USART_RX_BUF;
		while(*cmd == ' ' || *cmd == '\t') cmd++; // 去除前导空格

		if(cmd[0] != '\0')
		{
				/* 1. 自检指令: TEST 或 CHECK (最高优先级匹配) */
				if(strncmp(cmd, "TEST", 4) == 0 || strncmp(cmd, "test", 4) == 0 ||
				   strncmp(cmd, "CHECK", 5) == 0 || strncmp(cmd, "check", 5) == 0)
				{
					printf("\r\n[CMD] Triggering Motor & Encoder Self-Test...\r\n");
					Motor_Encoder_OpenLoop_SelfTest();
				}
				/* 1.1 极对数精确标定指令: PP [1/2/3] */
				else if(strncmp(cmd, "PP", 2) == 0 || strncmp(cmd, "pp", 2) == 0)
				{
					int m_target = 0;
					if(cmd[2] >= '1' && cmd[2] <= '3') m_target = cmd[2] - '1';
					else if(cmd[2] == ' ' && cmd[3] >= '1' && cmd[3] <= '3') m_target = cmd[3] - '1';
					Motor_Measure_PolePairs((uint8_t)m_target);
				}
			/* 2. 遥测流开关: TELE <0/1> */
			else if(strncmp(cmd, "TELE", 4) == 0 || strncmp(cmd, "tele", 4) == 0)
			{
				telemetry_enabled = (uint8_t)(atoi(cmd + 4) != 0);
				printf("OK TELE:%d\r\n", telemetry_enabled);
			}
				/* 3. 控制模式切换: MODE <0/1> (0=开环, 1=闭环) */
				else if(strncmp(cmd, "MODE", 4) == 0 || strncmp(cmd, "mode", 4) == 0)
				{
					int m = atoi(cmd + 4);
					if(m == 1)
					{
						reset_closed_loop_state(-1);
						controller = Type_velocity;
						printf("OK MODE:1 (Closed-loop Speed)\r\n");
					}
					else if(m == 0)
					{
						controller = Type_velocity_openloop;
						printf("OK MODE:0 (Open-loop Speed)\r\n");
					}
					else
					{
						printf("ERR MODE format (Usage: MODE 1 for Closed-loop, MODE 0 for Open-loop)\r\n");
					}
				}
				/* 4. 紧急全停: STOP 或 S */
				else if(strncmp(cmd, "STOP", 4) == 0 || strncmp(cmd, "stop", 4) == 0 ||
				        ((cmd[0] == 'S' || cmd[0] == 's') && (cmd[1] == '\0' || cmd[1] == ' ' || cmd[1] == '\t')))
				{
					target = 0.0f;
					target_m1 = 0.0f;
					target_m2 = 0.0f;
					target_m3 = 0.0f;
					LQR_Balance_Enable(false);
					set_motor_enable(0, 0); // 紧急全停时硬件失能 DRV8313，确保电机完全脱开自由滑行
					setPhaseVoltage(0.0f, 0.0f, 0.0f, 0);
					setPhaseVoltage(0.0f, 0.0f, 0.0f, 1);
					setPhaseVoltage(0.0f, 0.0f, 0.0f, 2);
					printf("OK STOP (Hardware Disarmed)\r\n");
				}
			/* 5. 传感器切换: SENSOR <1/2> */
			else if(strncmp(cmd, "SENSOR", 6) == 0 || strncmp(cmd, "sensor", 6) == 0)
			{
				int t = atoi(cmd + 6);
				if (t == 1 || t == 2)
				{
					imu_active_type = (uint8_t)t;
					if (imu_active_type == IMU_TYPE_LSM6DSR) imu_online = (LSM6DSR_Init() == 0);
					else imu_online = (MPU6050_Init() == 0);
					printf("OK SENSOR:%d online=%d\r\n", imu_active_type, imu_online);
				}
				else
				{
					printf("ERR SENSOR format (Usage: SENSOR 1 for LSM6DSR, SENSOR 2 for MPU6050)\r\n");
				}
			}
					/* 6. 霍尔/磁编码角度查询: HALL 或 ENC */
					else if(strncmp(cmd, "HALL", 4) == 0 || strncmp(cmd, "hall", 4) == 0 ||
					        strncmp(cmd, "ENC", 3) == 0 || strncmp(cmd, "enc", 3) == 0)
					{
							int16_t r[3];
							float d[3];
							uint8_t o1 = (ENC_GetAngle(0, &r[0], &d[0]) == 0);
							uint8_t o2 = (ENC_GetAngle(1, &r[1], &d[1]) == 0);
							uint8_t o3 = (ENC_GetAngle(2, &r[2], &d[2]) == 0);
							printf("--- Motor Hall/Encoder Sensors (MT6701) ---\r\n"
							       "M1 (I2C1): Raw=%d (0x%04X), Angle=%.2f deg, Spd=%.2f rad/s, Online=%d\r\n"
							       "M2 (I2C2): Raw=%d (0x%04X), Angle=%.2f deg, Spd=%.2f rad/s, Online=%d\r\n"
							       "M3 (I2C3): Raw=%d (0x%04X), Angle=%.2f deg, Spd=%.2f rad/s, Online=%d\r\n",
							       r[0], (uint16_t)r[0], d[0], shaft_velocity[0], o1,
							       r[1], (uint16_t)r[1], d[1], shaft_velocity[1], o2,
							       r[2], (uint16_t)r[2], d[2], shaft_velocity[2], o3);
					}
			/* 7. 六轴陀螺仪与加速度计状态查询: IMU */
			else if(strncmp(cmd, "IMU", 3) == 0 || strncmp(cmd, "imu", 3) == 0)
			{
				uint8_t id = 0;
				if (imu_active_type == IMU_TYPE_LSM6DSR) id = LSM6DSR_Read_ID();
				else if (imu_active_type == IMU_TYPE_MPU6050) id = MPU6050_Read_ID();
				printf("--- IMU Sensor Status ---\r\n"
				       "Type: %s, Online: %d, WHO_AM_I: 0x%02X\r\n"
				       "Gyro (dps):  Gx=%.2f, Gy=%.2f, Gz=%.2f\r\n"
				       "Accel (g):   Ax=%.3f, Ay=%.3f, Az=%.3f\r\n",
				       imu_active_type == IMU_TYPE_LSM6DSR ? "LSM6DSRTR (SPI2)" : "MPU-6050 (Soft-I2C)",
				       imu_online, id,
				       imu_gyro[0], imu_gyro[1], imu_gyro[2],
				       imu_accel[0], imu_accel[1], imu_accel[2]);
			}
			/* 8. I2C 总线硬件扫描: SCAN */
			else if(strncmp(cmd, "SCAN", 4) == 0 || strncmp(cmd, "scan", 4) == 0)
			{
				int addr;
				printf("--- I2C Bus Scan (1-127) ---\r\nI2C1: ");
				for(addr = 1; addr < 128; addr++)
				{
					if(HAL_I2C_IsDeviceReady(&hi2c1, (uint16_t)(addr << 1), 2, 5) == HAL_OK)
						printf("0x%02X ", addr);
				}
				printf("\r\nI2C2: ");
				for(addr = 1; addr < 128; addr++)
				{
					if(HAL_I2C_IsDeviceReady(&hi2c2, (uint16_t)(addr << 1), 2, 5) == HAL_OK)
						printf("0x%02X ", addr);
				}
				printf("\r\nI2C3: ");
				for(addr = 1; addr < 128; addr++)
				{
					if(HAL_I2C_IsDeviceReady(&hi2c3, (uint16_t)(addr << 1), 2, 5) == HAL_OK)
						printf("0x%02X ", addr);
				}
				printf("\r\n--- End Scan ---\r\n");
			}
			/* 9. 电角度零位校准: ALIGN 或 CALIB */
			else if(strncmp(cmd, "ALIGN", 5) == 0 || strncmp(cmd, "align", 5) == 0 ||
			        strncmp(cmd, "CALIB", 5) == 0 || strncmp(cmd, "calib", 5) == 0)
			{
				printf("Starting Motor Alignment...\r\n");
				Motor_alignAll();
				printf("OK ALIGN\r\n");
			}
			/* 9. PID 参数设定与查询: PID <p> <i> <d> / PID1/2/3 <p> <i> <d> / PID / PID? */
			else if(strncmp(cmd, "PID", 3) == 0 || strncmp(cmd, "pid", 3) == 0)
			{
				float p_val = 0.0f, i_val = 0.0f, d_val = 0.0f;
				int motor_idx = 0;
				if(cmd[3] == '\0' || cmd[3] == '?' || (cmd[3] == ' ' && (cmd[4] == '?' || cmd[4] == '\0')))
				{
					printf("--- Velocity Loop PID & Filter Status ---\r\n"
					       "Mode: %s\r\n"
					       "M1 (TIM1): P=%.3f, I=%.3f, D=%.4f, Tf=%.4fs, Vlim=%.2fV\r\n"
					       "M2 (TIM3): P=%.3f, I=%.3f, D=%.4f, Tf=%.4fs, Vlim=%.2fV\r\n"
					       "M3 (TIM4): P=%.3f, I=%.3f, D=%.4f, Tf=%.4fs, Vlim=%.2fV\r\n",
					       controller == Type_velocity ? "CLOSED_LOOP (1)" : "OPEN_LOOP (0)",
					       pid_velocity[0].P, pid_velocity[0].I, pid_velocity[0].D, lpf_velocity[0].Tf, voltage_limit,
					       pid_velocity[1].P, pid_velocity[1].I, pid_velocity[1].D, lpf_velocity[1].Tf, voltage_limit,
					       pid_velocity[2].P, pid_velocity[2].I, pid_velocity[2].D, lpf_velocity[2].Tf, voltage_limit);
				}
				else if(cmd[3] == '1' || cmd[3] == '2' || cmd[3] == '3')
				{
					motor_idx = cmd[3] - '1';
					if(cmd[4] == '?' || (cmd[4] == ' ' && cmd[5] == '?'))
					{
						printf("OK PID%d: P=%.3f, I=%.3f, D=%.4f, Tf=%.4fs\r\n",
						       motor_idx + 1, pid_velocity[motor_idx].P, pid_velocity[motor_idx].I, pid_velocity[motor_idx].D, lpf_velocity[motor_idx].Tf);
					}
					else
					{
						int n = sscanf(cmd + 4, "%f %f %f", &p_val, &i_val, &d_val);
						if(n >= 2)
						{
							pid_velocity[motor_idx].P = p_val;
							pid_velocity[motor_idx].I = i_val;
							if(n == 3) pid_velocity[motor_idx].D = d_val;
							printf("OK PID%d: P=%.3f, I=%.3f, D=%.4f\r\n", motor_idx+1, pid_velocity[motor_idx].P, pid_velocity[motor_idx].I, pid_velocity[motor_idx].D);
						}
						else
						{
							printf("ERR PID format (Usage: PID%d <P> <I> [D])\r\n", motor_idx+1);
						}
					}
				}
				else
				{
					int n = sscanf(cmd + 3, "%f %f %f", &p_val, &i_val, &d_val);
					if(n >= 2)
					{
						int k;
						for(k = 0; k < 3; k++)
						{
							pid_velocity[k].P = p_val;
							pid_velocity[k].I = i_val;
							if(n == 3) pid_velocity[k].D = d_val;
						}
						printf("OK ALL PID: P=%.3f, I=%.3f, D=%.4f\r\n", p_val, i_val, d_val);
					}
					else
					{
						printf("ERR PID format (Usage: PID <P> <I> [D] or PID?)\r\n");
					}
				}
			}
			/* 9.0 速度低通滤波时间常数设定: TF <val> 或 TF1/2/3 <val> */
			else if(strncmp(cmd, "TF", 2) == 0 || strncmp(cmd, "tf", 2) == 0)
			{
				float tf_val = 0.0f;
				if(cmd[2] == '1' || cmd[2] == '2' || cmd[2] == '3')
				{
					int m = cmd[2] - '1';
					tf_val = (float)atof(cmd + 3);
					if(tf_val >= 0.001f && tf_val <= 0.100f)
					{
						lpf_velocity[m].Tf = tf_val;
						printf("OK TF%d: %.4fs\r\n", m + 1, lpf_velocity[m].Tf);
					}
					else printf("ERR TF range (0.001~0.100s)\r\n");
				}
				else
				{
					tf_val = (float)atof(cmd + 2);
					if(tf_val >= 0.001f && tf_val <= 0.100f)
					{
						int k;
						for(k = 0; k < 3; k++) lpf_velocity[k].Tf = tf_val;
						printf("OK ALL TF: %.4fs\r\n", tf_val);
					}
					else printf("ERR TF range (0.001~0.100s)\r\n");
				}
			}
				/* 9.1 平衡控制使能开关: BAL <0/1> */
				else if(strncmp(cmd, "BAL ", 4) == 0 || strncmp(cmd, "bal ", 4) == 0)
				{
					int en = atoi(cmd + 4);
					if(en == 1)
					{
						/* 确保电机驱动硬件使能并切入闭环 */
						set_motor_enable(0, 1);
						LQR_Balance_Enable(true);
						printf("OK BAL:1 (Balance Enabled, Mode=%d)\r\n", cubli_bal.mode);
					}
					else
					{
						LQR_Balance_Enable(false);
						printf("OK BAL:0 (Balance Disabled)\r\n");
					}
				}
				/* 9.2 平衡模式切换: BMODE <1/2/3/4> (1=M1边沿, 2=M2边沿, 3=M3边沿, 4=顶点3D) */
				else if(strncmp(cmd, "BMODE", 5) == 0 || strncmp(cmd, "bmode", 5) == 0 ||
				        strncmp(cmd, "BAL_MODE", 8) == 0 || strncmp(cmd, "bal_mode", 8) == 0)
				{
					char *p = cmd + 5;
					if(strncmp(cmd, "BAL_MODE", 8) == 0 || strncmp(cmd, "bal_mode", 8) == 0) p = cmd + 8;
					while(*p == ' ' || *p == '\t') p++;
					int bm = atoi(p);
					if(bm >= 1 && bm <= 4)
					{
						LQR_Balance_SetMode((BalanceMode_e)(bm - 1));
						printf("OK BMODE:%d\r\n", bm);
					}
					else
					{
						printf("ERR BMODE format (Usage: BMODE 1~3 for Edge M1~M3, 4 for 3D Corner)\r\n");
					}
				}
				/* 9.3 LQR 参数设定: LQR <Kp> <Kd> <Kw> [Ki] 或 LQR1/2/3 <Kp> <Kd> <Kw> [Ki] */
				else if(strncmp(cmd, "LQR", 3) == 0 || strncmp(cmd, "lqr", 3) == 0)
				{
					float kp = 0.0f, kd = 0.0f, kw = 0.0f, ki = 0.0f;
					int motor_idx = (int)cubli_bal.mode; // 默认对当前平衡电机调整
					char *p_str = cmd + 3;

					if(cmd[3] == '1' || cmd[3] == '2' || cmd[3] == '3')
					{
						motor_idx = cmd[3] - '1';
						p_str = cmd + 4;
					}
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

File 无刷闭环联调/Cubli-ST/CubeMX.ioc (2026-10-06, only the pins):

Mcu.UserName=STM32F407ZGTx
PA0-WKUP.Signal=S_TIM5_CH1
PA1.Signal=S_TIM5_CH2
PA10.Signal=USART1_RX
PA13.Signal=SYS_JTMS-SWDIO
PA14.Signal=SYS_JTCK-SWCLK
PA5.Signal=S_TIM2_CH1_ETR
PA6.Signal=S_TIM3_CH1
PA7.Signal=S_TIM3_CH2
PA8.Signal=I2C3_SCL
PA9.Signal=USART1_TX
PB0.Signal=S_TIM3_CH3
PB10.Signal=GPIO_Output
PB11.Signal=GPIO_Output
PB12.Signal=GPIO_Output
PB13.Signal=SPI2_SCK
PB14.Signal=SPI2_MISO
PB15.Signal=SPI2_MOSI
PB3.Signal=S_TIM2_CH2
PB6.Signal=I2C1_SCL
PB7.Signal=I2C1_SDA
PC6.Signal=S_TIM8_CH1
PC7.Signal=S_TIM8_CH2
PC9.Signal=I2C3_SDA
PD0.Signal=GPIO_Output
PD1.Signal=GPIO_Output
PD12.Signal=S_TIM4_CH1
PD13.Signal=S_TIM4_CH2
PD14.Signal=S_TIM4_CH3
PD2.Signal=GPIO_Output
PD5.Signal=USART2_TX
PD6.Signal=USART2_RX
PD7.Signal=GPIO_Input
PE11.Signal=S_TIM1_CH2
PE13.Signal=S_TIM1_CH3
PE9.Signal=S_TIM1_CH1
PF0.Signal=I2C2_SDA
PF1.Signal=I2C2_SCL
PG0.Signal=GPIO_Output
PG1.Signal=GPIO_Output
PG2.Signal=GPIO_Output
PG3.Signal=GPIO_Output
PG4.Signal=GPIO_Output
PG5.Signal=GPIO_Output
PG6.Signal=GPIO_Output
PG7.Signal=GPIO_Output
PG8.Signal=GPIO_Output
PH0-OSC_IN.Signal=RCC_OSC_IN
PH1-OSC_OUT.Signal=RCC_OSC_OUT

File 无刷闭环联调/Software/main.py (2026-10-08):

# -*- coding: utf-8 -*-
"""
Cubli 三轴无刷电机联调上位机 (PyQt5 + pyqtgraph + pyserial)
-------------------------------------------------------------------------
适用硬件: STM32F407ZGT6 + 3x DRV8313 (M1/M2/M3) + LSM6DSRTR / MPU-6050
         + 板载 ESP32-WROOM32E 无线链路
通信协议: 
  - 有线模式: USART2 (PD5-TX, PD6-RX), 115200 8N1
  - 无线模式: F407 USART1 (PA9/PA10) -> ESP32 (IO25/IO26) -> WiFi TCP :3333
    两种链路字节流协议完全一致, 可在下拉框中随时切换
主要特性:
  1. 无多余 emoji，工控简洁高对比度深色风格
  2. 左侧电机调控与参数面板，右侧 3D 姿态立方体与电机转速实时曲线
  3. 修复转速曲线显示异常问题 (采用示波器式平滑滚动时间窗，修复 autoRange 导致的数据出界)
  4. 纯 QPainter 高性能 3D 立方体引擎，与陀螺仪/加速度计互补滤波姿态实时同步，默认水平朝上
  5. 飞轮转速联动动画、坐标轴指示与鼠标自由旋转视角
  6. 支持 WiFi(TCP) 无线连接 ESP32 (AP 热点直连默认 192.168.4.1:3333)
  7. 修复 QComboBox 下拉弹层在系统深色模式下回落到暗色调色板的显示异常
"""

import sys
import time
import math
import re
import socket
import select
from collections import deque

import serial
import serial.tools.list_ports

from PyQt5.QtCore import (
    Qt, QThread, pyqtSignal, QTimer, QMutex, QMutexLocker, QPointF
)
from PyQt5.QtWidgets import (
    QApplication, QMainWindow, QWidget, QVBoxLayout, QHBoxLayout,
    QGridLayout, QGroupBox, QLabel, QPushButton, QComboBox,
    QSlider, QDoubleSpinBox, QCheckBox, QTextEdit, QLineEdit,
    QSplitter, QFrame, QMessageBox, QTabWidget, QStatusBar, QProgressBar,
    QScrollArea
)
from PyQt5.QtGui import (
    QFont, QColor, QPalette, QPainter, QPolygonF, QPen, QBrush,
    QLinearGradient, QRadialGradient, QPainterPath
)

import pyqtgraph as pg

# 配置 pyqtgraph 全局浅色高对比度样式
pg.setConfigOption('background', '#ffffff')
pg.setConfigOption('foreground', '#334155')
pg.setConfigOption('antialias', True)


# =========================================================================
# WiFi(TCP) 链路封装: 与 pyserial.Serial 接口语义对齐
# 用于连接板载 ESP32-WROOM32E 的 TCP 服务器 (默认 192.168.4.1:3333),
# 数据流与有线串口完全一致 ($TELE...# 帧 / ASCII 命令行)
# =========================================================================
class TcpLink:
    """TCP 链路, 提供 is_open / in_waiting / read / write / close 接口"""

    def __init__(self, host, port, timeout=0.1):
        self._sock = socket.create_connection((host, int(port)), timeout=3.0)
        self._sock.settimeout(timeout)
        self._sock.setsockopt(socket.IPPROTO_TCP, socket.TCP_NODELAY, 1)

    @property
    def is_open(self):
        return self._sock is not None

    def close(self):
        if self._sock is not None:
            try:
                self._sock.close()
            except Exception:
                pass
            self._sock = None

    def write(self, data):
        if self._sock is None:
            raise OSError("TCP link closed")
        self._sock.sendall(data)

    @property
    def in_waiting(self):
        if self._sock is None:
            return 0
        try:
            readable, _, _ = select.select([self._sock], [], [], 0)
            if not readable:
                return 0
            return len(self._sock.recv(65536, socket.MSG_PEEK))
        except Exception:
            return 0

    def read(self, n=1):
        if self._sock is None:
            return b""
        try:
            return self._sock.recv(min(int(n), 65536))
        except socket.timeout:
            return b""
        except Exception:
            return b""


# =========================================================================
# 禁用鼠标滚轮调整的自定义控件 (防止在滚动面板时误触修改速度与参数)
# =========================================================================
class NoWheelSlider(QSlider):
    """水平滑块组件：禁用鼠标滚轮，防止在滚动左侧控制面板时误触更改速度"""
    def wheelEvent(self, event):
        event.ignore()


class NoWheelDoubleSpinBox(QDoubleSpinBox):
    """数值输入框组件：禁用鼠标滚轮，防止滚轮滑动时误改转速与参数"""
    def wheelEvent(self, event):
        event.ignore()


# =========================================================================
# 串口后台通信工作线程 (QThread)
# =========================================================================
class SerialWorker(QThread):
    """串口数据收发与协议解析线程"""
    sig_connected = pyqtSignal(str, int)
    sig_disconnected = pyqtSignal()
    sig_error = pyqtSignal(str)
    sig_log_rx = pyqtSignal(str)
    sig_mode_changed = pyqtSignal(int)
    sig_pid_received = pyqtSignal(int, float, float, float)
    sig_log_tx = pyqtSignal(str)
    sig_telemetry = pyqtSignal(dict)
    sig_test_step = pyqtSignal(str)     # 自检单步进度: "M1", "M2", "M3"
    sig_test_report = pyqtSignal(dict)  # 自检总结结果字典

    # 自检协议正则:
    # 步骤帧: $TEST_STEP,M1#
    # 总结帧: $TEST_REPORT,M1:PASS:100:432.1,M2:PASS:100:428.9,M3:PASS:100:435.0,ALL:PASS#
    TEST_STEP_PATTERN = re.compile(r'\$TEST_STEP,(M[123])#')
    TEST_REPORT_PATTERN = re.compile(
        r'\$TEST_REPORT,'
        r'M1:([A-Za-z0-9_()]+):(\d+):([0-9.-]+),'
        r'M2:([A-Za-z0-9_()]+):(\d+):([0-9.-]+),'
        r'M3:([A-Za-z0-9_()]+):(\d+):([0-9.-]+),'
        r'ALL:(PASS|FAIL)#'
    )

    # 遥测帧正则:
    # 基础帧: $TELE,M1:%.2f,M2:%.2f,M3:%.2f,Vq:%.2f,EN:%d%d%d,A1:%.2f,A2:%.2f,A3:%.2f#
    # 扩展帧1 (IMU): ...,Gx:%.1f,Gy:%.1f,Gz:%.1f,Ax:%.2f,Ay:%.2f,Az:%.2f#
    # 扩展帧2 (IMU + Hall): ...,H1:%.1f,H2:%.1f,H3:%.1f#
    # 扩展帧3 (Closed-loop Speed): ...,S1:%.2f,S2:%.2f,S3:%.2f#
    TELE_PATTERN = re.compile(
        r'\$TELE,'
        r'M1:([+-]?\d+(?:\.\d+)?),'
        r'M2:([+-]?\d+(?:\.\d+)?),'
        r'M3:([+-]?\d+(?:\.\d+)?),'
        r'Vq:([+-]?\d+(?:\.\d+)?),'
        r'EN:([01])([01])([01]),'
        r'A1:([+-]?\d+(?:\.\d+)?),'
        r'A2:([+-]?\d+(?:\.\d+)?),'
        r'A3:([+-]?\d+(?:\.\d+)?)(?:,'
        r'Gx:([+-]?\d+(?:\.\d+)?),'
        r'Gy:([+-]?\d+(?:\.\d+)?),'
        r'Gz:([+-]?\d+(?:\.\d+)?),'
        r'Ax:([+-]?\d+(?:\.\d+)?),'
        r'Ay:([+-]?\d+(?:\.\d+)?),'
        r'Az:([+-]?\d+(?:\.\d+)?))?'
        r'(?:,H1:([+-]?\d+(?:\.\d+)?),'
        r'H2:([+-]?\d+(?:\.\d+)?),'
        r'H3:([+-]?\d+(?:\.\d+)?))?'
        r'(?:,S1:([+-]?\d+(?:\.\d+)?),'
        r'S2:([+-]?\d+(?:\.\d+)?),'
        r'S3:([+-]?\d+(?:\.\d+)?))?'
        r'(?:,Pit:([+-]?\d+(?:\.\d+)?),'
        r'Rol:([+-]?\d+(?:\.\d+)?),'
        r'Bal:(\d+))?#'
    )
    def __init__(self):
        super().__init__()
        self.ser = None
        self.is_running = False
        self.mutex = QMutex()
        self.tx_queue = deque()

    def connect_port(self, port_name, baud_rate=115200):
        """请求连接串口"""
        try:
            if self.ser and self.ser.is_open:
                self.ser.close()
            self.ser = serial.Serial(
                port=port_name,
                baudrate=baud_rate,
                bytesize=serial.EIGHTBITS,
                parity=serial.PARITY_NONE,
                stopbits=serial.STOPBITS_ONE,
                timeout=0.1
            )
            self.is_running = True
            if not self.isRunning():
                self.start()
            self.sig_connected.emit(port_name, baud_rate)
        except Exception as e:
            self.sig_error.emit(f"无法打开串口 {port_name}: {str(e)}")
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

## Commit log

2026-03-31 测试提交
    [资源分配0331.xlsx]
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2026-06-08 fixed path invalid
    [完备资源分配0424.xlsx]
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2026-06-08 SimpleFOC移植验证
    [完备资源分配0424.xlsx]
2026-06-08 fixed bugs
    [完备资源分配0424.xlsx]
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2026-09-22 硬件测试 霍尔 上位机调速器 陀螺仪
    硬件测试 霍尔 上位机调速器 陀螺仪
    过测
    [完备资源分配0424.xlsx]
2026-09-22 Revise README with updated version history
    Updated version history and details for Cubli STM32F407ZGT6 project, including changes to alpha versions and power management.
2026-09-22 优化上位机UI风格与三维姿态显示，适配多分辨率并重构静止地面
    1. UI素雅工业风重构:
    - 去除所有无用彩色条框(电机卡片、三轴同步、参数配置等)，统一深色工控朴素基调
    - 优化指标栏与按钮排版，仅为紧急停止保留标准工控安全警示色
    2. 屏幕与控件显示适配:
    - 左侧控制面板引入自适应 QScrollArea 容器，根除小屏幕垂直挤压导致按钮与文本无法显示的缺陷
    - 右侧顶部指标卡片重构为 2x3 网格布局，彻底解决单行 6 卡片文字截断溢出
    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
    [完备资源分配0424.xlsx]
2026-09-22 基于三个MT6701磁编码器实现三轴无刷电机速度闭环控制与联调监控
    1. MT6701 多圈角度解算与速度低通滤波:
    - 优化 I2C 读取超时 (2ms)，杜绝总线离线阻塞 CPU 主循环
    - 实现 0~2PI 跨圈检测与连续角位移跟踪
    - 结合微秒级时基差分计算转速，引入一阶低通滤波 (Tf=15ms) 抑制阶梯量化噪声
    2. 电角度零位自动对齐与旋向辨识 (Motor_alignSensor / Motor_alignAll):
    - 上电及指令自动激励定位转子，测定正向/反向旋转方向
    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
2026-09-24 3D文件更新
    [无刷霍尔底座.SLDPRT, 无刷霍尔底座.STL]
2026-09-25 优化速度闭环控制算法，消除齿槽死区抖动并修复自检零电角校准
    1. 电机极对数高精度实测:
    - 经 11 个电周期微步细分实测验证，三轴磁极对数确为 7 极对 (14 磁极)，排除极对数配置错误。
    2. 根除自检零电角对齐失控 Bug:
    - 修复 Motor_Encoder_OpenLoop_SelfTest 在零电角采样前关断驱动使能的致命缺陷，恢复对齐时的受力吸合；
    - 自检通过切换闭环瞬间彻底复位 PID 历史误差积分与滤波器，杜绝切入闭环时产生积分冲击飞车。
    3. 闭环极性与传感器滤波重构:
    - 纠正速度闭环转矩输出反向问题，恢复负反馈闭环极性；
    - 将 MT6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
    [BLDCMotor.c, MyProject.h, delay.c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]
2026-09-25 全面对齐官方 SimpleFOC 闭环与 SVPWM 架构，消除脉冲抖动并实现全速域丝滑旋转
    1. 消除人为摩擦前馈与脉冲根因:
    - 彻底移除人为叠加的 0.55V 摩擦前馈偏置，消除控制器与小无刷电机的内部角力抖动；
    - 引入 USART2 异步环形发送缓冲区 (1024 字节) 与硬件 TXE 中断，将 printf 耗时从 15ms 阻塞降至微秒级瞬间入队，彻底消灭 25Hz 遥测阻塞脉冲；
    - 将测速低通滤波时间常数对齐官方 SimpleFOC 推荐的 15ms，消除 80ms 超大滤波相移引起的低频极限环振荡。
    2. 全面对齐官方 SimpleFOC SpaceVectorPWM 空间矢量调制:
    - 重构 setPhaseVoltage，采用官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
2026-09-25 调优速度环消除15-25rad/s高频振动与零速抖动，调速上限提升至60rad/s并将电压拉满
    1. 根治零速高频自激颤振:
    - 优化零速待机逻辑: 只要目标速度为 0 即无条件输出 0V 相电压并彻底复位积分器，杜绝因编码器微小采样噪声离开死区引发的自激高频蜂鸣。
    2. 根治 15~25 rad/s 高频振荡:
    - 经动力学分析，该区间的高频振荡由低通滤波相移滞后叠加过大积分增益导致。将 LPF 时间常数优化为 8ms，降低高频相移，重构 PID 增益为 P=0.15, I=1.20，大幅提升闭环相位裕度，实测 15~25 rad/s 振动彻底消失。
    3. 上位机与固件极速提升至 60 rad/s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
2026-09-25 重构上位机UI为现代明亮浅色主题并禁用调速滚轮误触
    1. 禁用速度滑块鼠标滚轮:
    - 封装 NoWheelSlider 与 NoWheelDoubleSpinBox 自定义控件，彻底拦截鼠标滚轮事件；
    - 避免在滚轮滑动左侧控制面板时意外误改电机转速。
    2. 全面重构界面为现代工控浅色主题:
    - 主窗口背景采用 Slate-50 (#f8fafc)，控制卡片采用纯白底色 (#ffffff) 配合精致边框 (#e2e8f0) 与深灰文字 (#0f172a)；
    - 波形图表背景切换为高对比度白底 (#ffffff)，栅格柔和 (#cbd5e1)，重新调优六轴波形曲线色彩；
    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
2026-09-26 3D文件更新
    3D资源文件 主框架 动量轮 仿真装配体等
    [2804无刷.SLDPRT, 3D_MBO_2026-09-26.step, 主框架-260926-1936.STL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]
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2026-10-01 主框架螺纹孔更新
    [主框架-261002-0303.STL, 主框架.SLDPRT]
2026-10-06 动量轮2D
    [动量轮-260927-1833.STL, 动量轮-261006-1415.STL, 动量轮.SLDPRT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]
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2026-10-07 3D资源更新
    [主框架-261007-1904.STL, 主框架.SLDPRT]
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2026-10-07 无效文件清理
    [动量轮CAD.dwg]
2026-10-07 2D/3D机械结构资源整理结构重组
    [2804无刷.SLDPRT, 3D_MBO_2026-09-26.step, 主框架-260926-1936.STL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]
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2026-10-07 Revert "Create 下单参数 304酸白板不锈钢材 5mm 表面去毛刺.txt"
    This reverts commit bd6f2aa854e8b64a1da42ebf99a1c3aac734ff95.
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2026-10-08 3D机械孔径变更
    [动量轮限位器-261008-2106.STL, 动量轮限位器.SLDPRT, 无刷霍尔底座-261008-2051.STL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]
2026-10-08 3D微调
    [无刷霍尔底座-261008-2119.STL, 无刷霍尔底座-261008-2200.STL, 无刷霍尔底座.SLDPRT]
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2026-10-12 Stabilize FOC and encoder safety
    This update hardens the Cubli firmware by zeroing stalled motor targets, enforcing ramped velocity changes, rejecting uncalibrated/offline encoders, and adding PID anti-windup/headroom logic. It also switches the default debug link to USART1 (ESP32 wireless path), fixes hardware quad encoder enablement, and updates the software/UI docs for the new communication and safety behavior.
2026-10-12 Add MB schematic review report
    Added a detailed Cubli MB schematic review report covering pin assignments, power/protection, charging, key switch, and debug findings against the netlist and firmware. Also refreshed the CubeMX MDK-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
2026-10-12 正交角度结算与问题修复
2026-10-13 电角度对齐/修复部分问题
2026-10-13 上位机串口阻塞卡顿修复 转角纠正
2026-10-13 feat: add guarded motor diagnostics and assisted edge balance
2026-10-13 feat: add MCU-timed torque probes for edge commissioning
2026-10-13 feat: edge pose balancing and motor diagnostics commissioning
2026-10-13 feat: edge torque probes, held trials and trip20 alignment
2026-10-14 fix: ramp wheel feedback during assisted balance handover
2026-10-14 docs: align commissioning record with current commit history
2026-10-14 feat: add CAD-based wheel inertia and offline balance estimates
2026-10-14 feat: support 60-degree fixture cutoff and log hands-off torque probe
2026-10-14 feat: widen bounded fixture torque and wheel protection with test evidence
2026-10-14 test: confirm M1 body direction with paired B-endpoint torque probes
2026-10-14 feat: add bounded long torque impulses and verify hands-off B-to-A motion
2026-10-14 fix: disable dropdown wheel changes and expose M1 balance preparation
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2026-10-14 Add mechanical patch strip model
    Add the patch strip in SolidWorks and STL formats. Update the CubeMX workspace layout state.
2026-10-14 test: revalidate repaired motors and identify M2 M3 body axes
2026-10-14 feat: support per-axis edge trials and verify M2 torque direction
2026-10-14 test: record calibration recovery after battery reset
2026-10-14 test: verify M3 torque sign and record guarded edge trials
2026-10-14 test: save M3 edge balance after reference and wheel-gain correction
2026-10-14 feat: add independent yaw damping for corner balance
2026-10-14 fix: wait for stable rotor positions during sensor alignment
2026-10-14 feat: add live pose guidance and tighten corner entry window
2026-10-14 feat: enable automatic corner balance with retry and protection
    LQR_StartAuto accepts corner mode; LQR_AutoPoseReady gates corner entry on all three motors, axes, directions and wheel speeds below 5 rad/s. STATE reports the maximum wheel speed for corner mode; BAUTO error text updated. Harness gains a corner auto suite (arming prerequisites, entry gates, 20 deg trip retry, third-axis full-speed retry, overspeed exit) and the old corner BAUTO rejection is removed. Test runners write their build script in the ANSI codepage so cmd.exe reads the Chinese workspace path correctly.
2026-10-14 feat: add long-run corner auto diagnostic and upper-computer corner profile
    New serial_corner_auto.py arms BAUTO for corner mode, records every balancing attempt with its protection reason, re-enters automatically after tilt/full-speed stops, and keeps host backstops above the firmware thresholds (wheel 360, tilt 28 deg, rate 4 rad/s). Upper computer gains a verified-corner profile button (fixed 23.44/50 deg reference, 80/5/-0.030/0, BYAW 3) with ack-gated load, enables the auto button for corner mode with mode-aware labels, and reports the corner detection status. Simulated-device and UI tests cover arming prerequisites, ack flows, retry re-entry and backstop exits.
2026-10-14 build: CubeMX-corner-auto firmware with corner automatic balance
    I2C build, 38 inputs, 0 errors/0 warnings, ROM 47180 bytes. All regression suites pass: firmware harness (with the new corner auto suite), UART harness, quad tests, 38 upper-computer cases and 18 corner diagnostic cases.
2026-10-14 flash: CubeMX-corner-auto verified on the board; document corner auto mode
    ST-LINK download verified and MCU reset; boot reports CornerStart:1 with all motors disabled, so the board runs the new firmware. Corner auto operating instructions and command table updated for the single-point long-run workflow.
2026-10-14 feat: corner tilt-trim (BTRIM) firmware with telemetry and harness cover
    Adds the corner tilt-error integral (default 2.0, frozen while the output saturates, cleared on disarm) with BTRIM 0..10 command, Trim1..3/BTrim/TrimTune in STATE and T1..T3 in the corner FAST block. Harness covers the trim sign, clamp, disarm clearing and edge-mode isolation alongside the corner auto suite.
2026-10-14 feat: corner wind-up analysis, settle-reference iteration and closed-loop model
    analyze_corner_windup.py fits dV/dt against wheel speed and extracts the settled pose (--settle) to emit the next --reference-gravity candidate; corner_loop_model.py rebuilds the 15-state firmware lo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
2026-10-15 fix: keep -0.03 wheel gain default after Kw=0 hardware failures
    Two runs at Kw=0 fell in 1.6-2.4s (one with a clean 1.1deg entry on a fresh battery) while -0.03 ran 8-12.5s, so the script default returns to the hardware-verified baseline and the closed-loop model prints the caveat that its Kw=0 preference stays unproven until the model gap (unmodeled friction/delay) closes. Corner suite green (18).
2026-10-15 flash: re-verify CubeMX-corner-trim via SWD at 1MHz
    Second flash of the corner-trim build after the device returned: SWD connect at 4MHz failed to read the core ID, 480k-2MHz connected, hex written at 0x08000000 and download verified; boot readback shows TrimTune:1/BTrim:2.0/CornerStart:1 with all motors disabled. flash_verify.log added to the build-dir allowlist.
2026-10-15 docs: rewrite single-point balance notes for the full session; back up new runs
    Self-contained commissioning document now covers the whole session: firmware/script/UI/test change inventory, all 17 attempts with entry quality, the rejected positive-Kw and Kw=0 experiments, the cl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
2026-10-15 build: flash reviewed corner firmware and record disabled-board verification
2026-10-15 test: repeat three-axis preparation after battery reset
2026-10-15 build: flash two-second half-degree corner entry and verify board configuration
2026-10-15 fix: make preparation logging tolerant and verify new-entry calibration
2026-10-15 test: preserve reference comparison and prepare isolated wheel-feedback trial
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2026-10-15 Record old-reference failure and isolate wheel feedback next
2026-10-15 Record wheel-feedback isolation and plan passive gravity check
2026-10-15 Enable complete corner feedback at handover with idle-wheel guard
2026-10-15 Record eight-second repeat protection and isolate M3 wheel coefficient
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2026-10-15 Fix six-place UART gain readback and preserve rejected pre-arm trial
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2026-10-15 Fix stale pose overwrite during corner probe handover and test all axes
2026-10-16 Keep cleanup running after partial fault telemetry and shorten probe handover
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

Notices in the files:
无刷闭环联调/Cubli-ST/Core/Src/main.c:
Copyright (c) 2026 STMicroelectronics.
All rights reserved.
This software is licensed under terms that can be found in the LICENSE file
